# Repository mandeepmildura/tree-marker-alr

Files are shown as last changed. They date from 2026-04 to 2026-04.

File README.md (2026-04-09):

# Tree Marker ALR

GPS-triggered relay marker for precision orchard row planting.  
Fires an on-board relay at each tree grid intersection using RTK accuracy from an AgOpenGPS setup.

**Hardware:** [KinCony ALR](https://www.kincony.com/esp32-lora-sx1278-gateway.html) (ESP32-S3 + SSD1306 OLED + relay)  
**Position source:** AgOpenGPS / AgIO via WiFi UDP — no separate GPS needed  
**Accuracy:** ~2–5 cm with F9P RTK  

---

## How it works

```
F9P RTK GPS → AIO Teensy → UDP broadcast (port 9999) → AgIO on tablet
                                   ↓
                         ESP32-S3 on ALR listens on same WiFi
                         → parses $GNGGA → checks grid → fires relay
```

The ALR, your Windows tablet (AgIO), and AIO Teensy Ethernet all connect to the same phone hotspot in the tractor cab. No extra GPS wiring required.

---

## Hardware wiring

| Connection | Details |
|---|---|
| Power | 12–24V DC to ALR terminals |
| Relay output | ALR relay COM + NO → existing solenoid trigger circuit |
| WiFi | Same hotspot as AgOpenGPS tablet |

That's it. OLED, relay, and WiFi are all on-board.

---

## Setup

### 1. Install Arduino IDE dependencies

- Board package: **ESP32 by Espressif** — add this URL in board manager:  
  `https://raw.githubusercontent.com/espressif/arduino-esp32/gh-pages/package_esp32_index.json`
- Board: **ESP32S3 Dev Module**
- Libraries (Sketch → Manage Libraries):
  - `PubSubClient`
  - `Adafruit SSD1306`
  - `Adafruit GFX Library`

### 2. Edit config in `tree_marker.ino`

```cpp
const char* WIFI_SSID     = "YourHotspotName";
const char* WIFI_PASSWORD = "YourPassword";
const char* MQTT_HOST     = "your-id.s1.eu.hivemq.cloud";
const char* MQTT_USER     = "your-mqtt-user";
const char* MQTT_PASS     = "your-mqtt-pass";

const double ORIGIN_LAT   = -34.xxxxxx;   // First tree lat from AgOpenGPS
const double ORIGIN_LON   =  142.xxxxxx;  // First tree lon from AgOpenGPS
const double ROW_BEARING  =  90.0;        // AB line bearing from AgOpenGPS
const double ROW_SPACING  =   6.7;        // Metres
const double TREE_SPACING =   3.0;        // Metres
const int    NUM_ROWS     =  10;
const int    NUM_TREES    =  50;
```

### 3. Flash and test

1. Connect ALR via USB-C
2. Select **ESP32S3 Dev Module**, correct COM port
3. Upload
4. Open Serial Monitor (115200 baud)
5. OLED should show WiFi IP then "Waiting for AgIO"
6. Run AgOpenGPS simulation — drag cursor over a grid point — relay clicks

---

## MQTT topics

| Topic | Direction | Payload |
|---|---|---|
| `treemarker/status` | board → you | JSON heartbeat every 30s |
| `treemarker/hit` | board → you | `{"row":3,"tree":12,"dist":0.18,"lat":...,"lon":...}` |
| `treemarker/ota/url` | you → board | GitHub release .bin URL |
| `treemarker/ota/status` | board → you | `queued` / `starting` / `success` / `failed: ...` |
| `treemarker/restart` | you → board | Any payload triggers reboot |

---

## OTA firmware update via MQTT

1. Push a version tag to trigger a build and release:
   ```
   git tag v1.0.1
   git push origin v1.0.1
   ```
2. Wait for GitHub Actions to finish (~3 min)
3. Go to **Releases** → copy the `.bin` asset URL
4. Publish the URL to `treemarker/ota/url` via your MQTT client  
   (HiveMQ web client, MQTT Explorer, or Node-RED)
5. Board downloads, flashes, and reboots — monitor `treemarker/ota/status`

---

## Grid coordinate system

```
Tree (0,0) ─── Tree (0,1) ─── Tree (0,2) ───  ← Row 0 (ROW_BEARING direction)
    │                                          spacing = TREE_SPACING (3.0m)
Tree (1,0) ─── Tree (1,1) ─── Tree (1,2) ───  ← Row 1
    │
    ↕ ROW_SPACING (6.7m)
```

Origin `(ORIGIN_LAT, ORIGIN_LON)` = position of Tree (row=0, tree=0).  
`ROW_BEARING` = compass heading your rows run (get from AgOpenGPS AB line).

---

## Tuning

| Setting | Default | Notes |
|---|---|---|
| `HIT_RADIUS` | 0.35m | Tighten to 0.15m with solid RTK fix |
| `RELAY_PULSE_MS` | 600ms | Adjust for your solenoid / spray nozzle |
| `COOLDOWN_MS` | 2000ms | Prevents double-trigger on same tree |

---

## Project context

Part of the [AquaControl / Sunraysia Acres](https://github.com/mandeepMildura) precision ag toolkit.  
Mildura / Sunraysia region, Victoria, Australia.

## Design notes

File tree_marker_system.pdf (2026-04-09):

# GPS Tree Marker System

### Sunraysia Acres Pty Ltd — Mildura, Victoria

### Visual Feedback Options: KML Grid Overlay + Real-Time Web Dashboard

## 1. Project Overview

The Tree Marker system is a GPS-triggered paint marker that automatically fires a solenoid every time the tractor crosses a pre-calculated tree planting position. It piggybacks the existing AgOpenGPS RTK-GPS setup already on the tractor — no second GPS unit is needed.

Farm | Sunraysia Acres Pty Ltd, Mildura / Sunraysia, Victoria
Tractor | 1994–1997 Case IH 3230, 12V, hydrostatic power steering
GPS accuracy | Ardusimple SimpleRTK2B (u-blox F9P), RTK fix, ~2 cm
Controller | KinCony ALR board (ESP32-S3) — mounts on tractor
Marker | Existing electric paint solenoid, 12V — relay wired in series
Row spacing | 6.7 m between rows
Tree spacing | 3.0 m between trees within each row
Grid size | 10 rows × 50 trees = 500 tree positions per field

How it works — data flow

Ste p | What happens | Device
1 | F9P RTK GPS locks to ~2 cm fix | Ardusimple on AIO board
2 | AIO Teensy 4.1 forwards NMEA over Ethernet UDP → port 9999 | AIO v4.5 Standard
3 | AgIO (Windows tablet) receives position — also broadcasts to subnet | Tablet in cab
4 | KinCony ALR receives $GNGGA sentence over WiFi UDP | ALR board on tractor
5 | ALR compares GPS position against pre-calculated tree grid | ESP32-S3 firmware
6 | Within 35 cm of a tree point → GPIO 48 HIGH for 600 ms | ALR relay
7 | Relay fires solenoid → paint mark on ground | Paint sprayer

The tree grid is pre-calculated from a field survey origin point and stored in firmware. Grid maths uses flat-earth distance — accurate to <1 mm at orchard scales.

## 2. Why Visual Feedback Matters

The relay fires automatically and the OLED on the ALR board confirms each hit. However, for a commercial planting run across 500+ positions, the operator needs two additional things:

Need | Without feedback | With Options B + C
Pre-run check | No way to verify grid alignment before starting | KML overlay in Google Earth confirms grid matches real field boundaries
During run | Operator can't tell if a mark was missed | Live web dashboard shows each hit in real time — gaps are immediately visible
Post-run record | No permanent record of what was marked | Dashboard hit history + MQTT log = permanent GPS-stamped record of every mark
Missed-tree recovery | Must re-drive entire row | Dashboard shows exactly which tree was missed — drive back to that point only

## 3. Option C — KML Tree Grid Overlay

What it is: A standard KML file containing all 500 tree positions as placemarks and 10 row lines. Opens in Google Earth on any device. Used for pre-run alignment checks and post-run review. The file is auto-generated from the same grid parameters as the firmware — they are always in sync.

What the KML contains
- 500 yellow dot placemarks — one per tree, labelled R0T0 … R9T49
- 10 green row lines — one per row, showing direction of travel
- Document name and grid parameters embedded in description

How to use it — pre-run alignment check

Ste p | Action
1 | Open tree_grid.kml in Google Earth on phone or tablet
2 | Navigate to the field — the 500 dots appear on satellite imagery
3 | Compare dot positions against existing tree rows / fence lines
4 | If alignment is off, adjust ORIGIN_LAT, ORIGIN_LON or ROW_BEARING in firmware and regenerate
5 | When dots match reality, origin and bearing are confirmed — proceed to field run

How to use it — post-run review
- Open the KML in Google Earth after the run
- Cross-reference with the web dashboard hit history (Option B) to identify any missed positions
- Screenshot the overlay for farm records / neighbour sharing

Important note on coordinates

The KML currently uses placeholder coordinates (origin -34.200000, 142.150000). Before the farm run, a field survey must establish the real ORIGIN_LAT, ORIGIN_LON, and ROW_BEARING from the actual orchard. Once those are measured and entered, re-run make_kml.py (one command) and the KML updates automatically.

Field survey procedure

# | Measurement | Tool | Where to enter

1 | Stand the tractor at tree position (0,0) — first tree of first row. Record lat/lon from AgOpenGPS display. | AgOpenGPS + F9P RTK | ORIGIN_LAT, ORIGIN_LON in firmware
2 | Drive to the end of row 0 — last tree. Note the AgOpenGPS AB line bearing. | AgOpenGPS AB line bearing readout | ROW_BEARING in firmware (degrees, 0=N, 90=E)
3 | Count actual rows and trees if different from 10×50. | Walk the field | NUM_ROWS, NUM_TREES in firmware

## 4. Option B — Real-Time Web Dashboard

What it is: A single HTML file that opens in any browser (phone, tablet, laptop). It connects to the HiveMQ MQTT broker over a secure WebSocket and displays a live map. Every time the relay fires, a green marker drops on the map at the exact GPS coordinates of the hit. No app installation required.

How it works

Component | Technology | Role
Map display | Leaflet.js (open-source, offline-capable) | Renders satellite/street tile map with tree dots
Live updates | MQTT over WebSocket (port 8884, TLS) | Receives hit events from HiveMQ Cloud in real time
Broker | HiveMQ Cloud — eb65c13e....hivemq.cloud | Relays MQTT messages from ALR board to browser
Planned trees | GeoJSON generated from grid parameters | All 500 positions shown as grey dots on load
Hit markers | Green Leaflet markers, timestamped | Drop on map as each relay fires
No server | Pure browser HTML/JS — no backend needed | Open the file directly, works on any device

What you see on the dashboard
- Grey dots — all 500 planned tree positions (loaded at startup from grid maths)
- Green markers — confirmed hits, appearing in real time as the tractor drives
- Popup on click — shows Row, Tree, distance from centre, timestamp, lat/lon
- Hit counter — total marks fired this session
- Connection indicator — green/red dot showing MQTT link status

How to use it during a run

Ste p | Action
1 | Ensure phone/tablet is on the same WiFi hotspot as the ALR board
2 | Open tree_marker_dashboard.html in Chrome or Safari — map loads automatically
3 | Drive the first row — green markers should appear every 3.0 m

4 | If a grey dot stays grey after passing it, that tree was missed — note the Row/Tree number
5 | After completing all rows, screenshot the dashboard for farm records
6 | Hit history is also in HiveMQ Cloud — accessible from any browser after the run

MQTT message format (what the board sends)
Topic: treemarker/hit

{"row":3, "tree":12, "dist":0.18, "lat":-34.3171234, "lon":142.1562345, "hits":37}
Every hit publishes one JSON message. The dashboard subscribes to this topic and plots each message as a map marker. The full hit log is retained in HiveMQ for post-run review.

## 5. Combined Workflow — A to Z

Phase | Task | Tool | Status
Field survey | Drive to tree (0,0) with RTK lock. Record lat/lon + AB line bearing. | AgOpenGPS on tablet | Pending — do before farm run
Firmware update | Enter real ORIGIN_LAT, ORIGIN_LON, ROW_BEARING, NUM_ROWS, NUM_TREES. Flash board. | Arduino IDE / arduino-cli | Pending — after survey
KML update | Re-run make_kml.py with real coordinates. New KML in 5 seconds. | Python script in repo | Pending — after survey
Pre-run check | Open updated KML in Google Earth. Confirm 500 dots match real field. | Google Earth on phone | Pending — before run
Dashboard open | Open tree_marker_dashboard.html in browser on phone. | Any browser | Ready — build in progress
Farm run | Drive rows. Relay fires at each tree. Dashboard shows live hits. | Tractor + ALR board | Pending — farm visit
Post-run review | Screenshot dashboard. Cross-check KML vs green hit markers. | Dashboard + Google Earth | Pending — after run
Records | Full hit log in HiveMQ Cloud — row, tree, GPS coords, timestamp for every mark. | HiveMQ Cloud console | Automatic — already active

## 6. System Specifications

Firmware version | v1.0.0
Board | KinCony ALR — ESP32-S3-WROOM-1U N16R8
Relay | GPIO 48, AC250V / 10A, volt-free contact
OLED | SSD1306 128×64, I2C (SDA 39, SCL 38)
WiFi | 2.4 GHz 802.11n — connects to phone hotspot
UDP input | Port 9999 — $GNGGA from AgIO broadcast
Hit radius | 0.35 m from tree centre

Relay pulse | 600 ms ON per hit
Cooldown | 2000 ms minimum between same-spot hits
MQTT broker | HiveMQ Cloud (TLS port 8883)
Broker host | eb65c13ec8ab480a9c8492778fdddda8.s1.eu.hivemq.cloud
MQTT client ID | tree-marker-alr-01
Status topic | treemarker/status (heartbeat every 30 s)
Hit topic | treemarker/hit (JSON per relay fire)
OTA topic | treemarker/ota/url (send GitHub .bin URL to update)
Restart topic | treemarker/restart (any payload reboots board)
GitHub repo | github.com/mandeepmildura/tree-marker-alr

## 7. Next Steps

# | Task | Notes

1 | Complete field survey at Mildura farm | Measure ORIGIN_LAT/LON and ROW_BEARING with RTK fix
2 | Update firmware config + reflash | Use OTA update over MQTT — no USB cable needed at farm
3 | Regenerate KML with real coordinates | Run make_kml.py — takes 5 seconds
4 | Open KML in Google Earth — verify grid alignment | Do this before starting the planting run
5 | Open web dashboard on phone | Confirm MQTT connection indicator is green
6 | Drive first row slowly — confirm relay fires every 3.0 m | Watch dashboard for green hits and listen for relay clicks
7 | Proceed with full planting run | Dashboard provides real-time hit confirmation

Document prepared by Claude Code — April 2026 — For internal use, Sunraysia Acres Pty Ltd

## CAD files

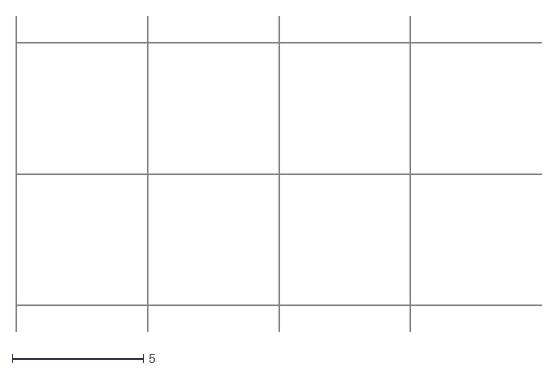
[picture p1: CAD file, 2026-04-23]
tests/sample_grid.dxf
20.0 x 12.0

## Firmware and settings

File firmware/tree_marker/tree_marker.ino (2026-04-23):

// ================================================================
//  Tree Row Marker — KinCony ALR (ESP32-S3)
//  Receives RTK position from AgOpenGPS via WiFi UDP
//  Fires on-board relay at each tree grid intersection
//
//  Repo:  https://github.com/mandeepMildura/tree-marker-alr
//  Board: KinCony ALR  https://www.kincony.com/esp32-lora-sx1278-gateway.html
//  IDE:   ESP32S3 Dev Module  (esp32 by Espressif, 2.x)
// ================================================================

#include <Arduino.h>
#include <WiFi.h>
#include <WiFiClientSecure.h>
#include <HTTPUpdate.h>
#include <PubSubClient.h>
#include <Wire.h>
#include <Adafruit_GFX.h>
#include <Adafruit_SSD1306.h>
#include <WebServer.h>
#include <Preferences.h>
#include <Update.h>
#include <HTTPClient.h>
#include <DNSServer.h>
#include <LittleFS.h>

// ── Firmware version (bumped on each release) ─────────────────
// 1.5.0 — DXF tree-grid upload: new /field/dxf endpoint parses LINE
//         entities, computes intersections, drives MODE_AB. Manual
//         anchor lat/lon supported as an alternative to AOG Field.txt.
//         Two outer perimeter lines exported as AgOpenGPS
//         TrackLines.txt (merge or stub) so autosteer tracks the
//         surveyed DXF edges.
#define FW_VERSION "1.5.0"

// ================================================================
//  COMPILED-IN DEFAULTS — overridden by Preferences after first save
// ================================================================
#define DEF_WIFI_SSID     "Mandeep"
#define DEF_WIFI_PASS     "rockyjungle161"
#define DEF_MQTT_HOST     "eb65c13ec8ab480a9c8492778fdddda8.s1.eu.hivemq.cloud"
#define DEF_MQTT_PORT     8883
#define DEF_MQTT_USER     "mandeep"
#define DEF_MQTT_PASS     "Gill@1977"
#define DEF_MQTT_CLIENT   "tree-marker-alr-01"
#define DEF_ORIGIN_LAT    -34.3166591
#define DEF_ORIGIN_LON    142.1562539
#define DEF_ROW_BEARING   180.0
#define DEF_ROW_SPACING   6.7
#define DEF_TREE_SPACING  3.0
#define DEF_NUM_ROWS      10
#define DEF_NUM_TREES     50
#define DEF_HIT_RADIUS    0.35
#define DEF_RELAY_PULSE   600

// Antenna → nozzle offset (v1.4.5). Both default to 0 so existing
// setups behave identically to v1.4.4 until calibrated.
#define DEF_FORE_AFT      0.0       // metres: positive = nozzle BEHIND antenna
#define DEF_LATERAL       0.0       // metres: positive = nozzle RIGHT of antenna centreline

// ── Grid mode ─────────────────────────────────────────────────
#define MODE_SIMPLE  0      // origin + bearing + spacings (bench/sim)
#define MODE_AB      1      // intersections[] grid (from AOG ABLines or DXF)

// Which source populated intersections[]. MODE_AB is the fire-detection
// mode; SRC_* distinguishes how the grid was built so boot can skip
// buildAbIntersections() when the source is DXF (no AB lines to resolve).
#define SRC_ABLINES  0
#define SRC_DXF      1

// Default AB-line names (match whatever you saved in AgOpenGPS)
#define DEF_ROW_NAME   "Row"
#define DEF_TREE_NAME  "Tree"

// Default DXF layer names for classifying LINE entities
#define DEF_ROW_LAYER  "Row"
#define DEF_TREE_LAYER "Tree"

// Default names for the two perimeter lines exported to TrackLines.txt
#define DEF_EDGE_ROW   "DXF-Row-Edge"
#define DEF_EDGE_TREE  "DXF-Tree-Edge"

// Max intersections we pre-compute and store in RAM.
// 2000 × 8 bytes = 16KB — comfortable on ESP32-S3.
#define MAX_INTERSECTIONS 2000

// Max boundary polygon vertices. 256 × 8 bytes = 2KB, and typical
// orchard boundaries have <100 points.
#define MAX_BOUNDARY 256

// ── AgIO UDP ──────────────────────────────────────────────────
#define UDP_PORT  8888

// ── MQTT topics ───────────────────────────────────────────────
#define T_STATUS      "treemarker/status"
#define T_HIT         "treemarker/hit"
#define T_OTA_URL     "treemarker/ota/url"
#define T_OTA_STATUS  "treemarker/ota/status"
#define T_RESTART     "treemarker/restart"

// ── Pin map ───────────────────────────────────────────────────
#define RELAY_PIN         48
#define OLED_SDA          39
#define OLED_SCL          38
#define SCREEN_W         128
#define SCREEN_H          64
#define SETUP_BUTTON_PIN   0       // DL button — hold at boot to force AP mode

// ── AP / setup mode ──────────────────────────────────────────
#define AP_SSID         "TreeMarker-Setup"
#define STA_TIMEOUT_MS  20000

// ── GitHub release API ───────────────────────────────────────
#define GH_LATEST_URL \
  "https://api.github.com/repos/mandeepMildura/tree-marker-alr/releases/latest"

// ================================================================
//  MUTABLE CONFIG (loaded from Preferences at boot)
// ================================================================
char   gWifiSsid[64];
char   gWifiPass[64];
char   gMqttHost[128];
int    gMqttPort;
char   gMqttUser[64];
char   gMqttPass[64];
double gOriginLat;
double gOriginLon;
double gRowBearing;
double gRowSpacing;
double gTreeSpacing;
int    gNumRows;
int    gNumTrees;
double gHitRadius;
int    gRelayPulse;
int    gUdpPort;
double gForeAft;         // + = nozzle behind antenna
double gLateral;         // + = nozzle right of centreline
double gHeading = 0;     // degrees, computed from consecutive fixes
double prevFixLat = 0, prevFixLon = 0;
bool   hasPrevFix = false;

// ── AB-mode state (loaded from NVS) ───────────────────────────
int    gGridMode;                 // MODE_SIMPLE or MODE_AB
char   gRowLineName[48];          // name of row AB line in ABLines.txt
char   gTreeLineName[48];         // name of tree AB line in ABLines.txt
double gFieldUtmE;                // (legacy — unused since v1.4.8)
double gFieldUtmN;                // (legacy — unused since v1.4.8)
int    gFieldZone;                // (legacy — unused since v1.4.8)
double gAnchorLat = 0;            // StartFix lat from AOG Field.txt
double gAnchorLon = 0;            // StartFix lon from AOG Field.txt
double gRowE, gRowN, gRowHdg;     // selected row AB line: point + heading(deg)
double gTreeE, gTreeN, gTreeHdg;  // selected tree AB line: point + heading(deg)
bool   gHasField  = false;        // true once Field.txt offsets are stored
bool   gHasLines  = false;        // true once both AB lines are selected
double gAbOriginE = 0;            // intersection of the two AB lines (row0/tree0) in local E/N
double gAbOriginN = 0;            // set by resolveActiveABLines()

// Raw ABLines.txt text held in RAM so user can re-pick lines without
// re-uploading. Persisted in NVS as "ab_raw" (<=3800 chars).
String gAbLinesRaw;

// ── DXF-mode state ────────────────────────────────────────────
// intersections[] may be populated from AOG ABLines (SRC_ABLINES) or
// from a DXF upload (SRC_DXF). The layer names are how we classify
// LINE entities inside the DXF; the edge names are how we tag the
// two outer perimeter lines that get exported to TrackLines.txt.
int  gGridSource = SRC_ABLINES;
char gRowLayer[24];
char gTreeLayer[24];
char gEdgeRowName[32];
char gEdgeTreeName[32];
// Generated TrackLines.txt content (merged or stubbed) — kept in
// NVS so the user can re-download without re-uploading the DXF.
String gTrackLinesOut;
// Outer row/tree perimeter line geometry (local E/N metres). Populated
// by pickOuterDxfLines() on each successful DXF upload. Heading is
// degrees in the AOG convention (0°=N, 90°=E, clockwise).
float  gEdgeRowX1 = 0, gEdgeRowY1 = 0, gEdgeRowX2 = 0, gEdgeRowY2 = 0;
float  gEdgeTreeX1 = 0, gEdgeTreeY1 = 0, gEdgeTreeX2 = 0, gEdgeTreeY2 = 0;
float  gEdgeRowHdg = 0, gEdgeTreeHdg = 0;
bool   gHasEdges = false;

// AB-mode geometry (declared up here so loadPrefs can populate them).
struct IPt { float e; float n; };
IPt  intersections[MAX_INTERSECTIONS];
int  numIntersections = 0;
IPt  boundary[MAX_BOUNDARY];
int  numBoundary = 0;
bool gHasBoundary = false;
int  lastRawIntersections = 0;  // pre-boundary-clip count, for UI

Preferences prefs;

void loadPrefs() {
  prefs.begin("tm", true);
  strlcpy(gWifiSsid,  prefs.getString("wifi_ssid",  DEF_WIFI_SSID).c_str(),  sizeof(gWifiSsid));
  strlcpy(gWifiPass,  prefs.getString("wifi_pass",  DEF_WIFI_PASS).c_str(),  sizeof(gWifiPass));
  strlcpy(gMqttHost,  prefs.getString("mqtt_host",  DEF_MQTT_HOST).c_str(),  sizeof(gMqttHost));
  gMqttPort    = prefs.getInt(   "mqtt_port",  DEF_MQTT_PORT);
  strlcpy(gMqttUser,  prefs.getString("mqtt_user",  DEF_MQTT_USER).c_str(),  sizeof(gMqttUser));
  strlcpy(gMqttPass,  prefs.getString("mqtt_pass",  DEF_MQTT_PASS).c_str(),  sizeof(gMqttPass));
  gOriginLat   = prefs.getDouble("origin_lat",  DEF_ORIGIN_LAT);
  gOriginLon   = prefs.getDouble("origin_lon",  DEF_ORIGIN_LON);
  gRowBearing  = prefs.getDouble("row_bearing", DEF_ROW_BEARING);
  gRowSpacing  = prefs.getDouble("row_spacing", DEF_ROW_SPACING);
  gTreeSpacing = prefs.getDouble("tree_space",  DEF_TREE_SPACING);
  gNumRows     = prefs.getInt(   "num_rows",    DEF_NUM_ROWS);
  gNumTrees    = prefs.getInt(   "num_trees",   DEF_NUM_TREES);
  gHitRadius   = prefs.getDouble("hit_radius",  DEF_HIT_RADIUS);
  gRelayPulse  = prefs.getInt(   "relay_pulse", DEF_RELAY_PULSE);
  gUdpPort     = prefs.getInt(   "udp_port",    UDP_PORT);
  gForeAft     = prefs.getDouble("fore_aft",    DEF_FORE_AFT);
  gLateral     = prefs.getDouble("lateral",     DEF_LATERAL);

  // AB-mode state
  gGridMode = prefs.getInt("grid_mode", MODE_SIMPLE);
  strlcpy(gRowLineName,  prefs.getString("row_name",  DEF_ROW_NAME ).c_str(), sizeof(gRowLineName));
  strlcpy(gTreeLineName, prefs.getString("tree_name", DEF_TREE_NAME).c_str(), sizeof(gTreeLineName));
  gFieldUtmE = prefs.getDouble("field_e", 0.0);
  gFieldUtmN = prefs.getDouble("field_n", 0.0);
  gFieldZone = prefs.getInt(   "field_z", 0);
  gAnchorLat = prefs.getDouble("anchor_lat", 0.0);
  gAnchorLon = prefs.getDouble("anchor_lon", 0.0);
  gHasField  = prefs.getBool(  "has_field", false);
  gHasLines  = prefs.getBool(  "has_lines", false);
  gRowE   = prefs.getDouble("row_e",   0);
  gRowN   = prefs.getDouble("row_n",   0);
  gRowHdg = prefs.getDouble("row_h",   0);
  gTreeE  = prefs.getDouble("tree_e",  0);
  gTreeN  = prefs.getDouble("tree_n",  0);
  gTreeHdg= prefs.getDouble("tree_h",  0);
  gAbLinesRaw = prefs.getString("ab_raw", "");
  gHasBoundary = prefs.getBool("has_bnd", false);
  numBoundary  = 0;
  if (gHasBoundary) {
    size_t want = prefs.getBytesLength("bnd_pts");
    if (want > 0 && want <= sizeof(boundary)) {
      prefs.getBytes("bnd_pts", boundary, want);
      numBoundary = want / sizeof(IPt);
    } else {
      gHasBoundary = false;
    }
  }

  // DXF-mode state
  gGridSource = prefs.getInt("grid_src", SRC_ABLINES);
  strlcpy(gRowLayer,     prefs.getString("row_lyr",   DEF_ROW_LAYER ).c_str(), sizeof(gRowLayer));
  strlcpy(gTreeLayer,    prefs.getString("tree_lyr",  DEF_TREE_LAYER).c_str(), sizeof(gTreeLayer));
  strlcpy(gEdgeRowName,  prefs.getString("edge_row",  DEF_EDGE_ROW ).c_str(),  sizeof(gEdgeRowName));
  strlcpy(gEdgeTreeName, prefs.getString("edge_tree", DEF_EDGE_TREE).c_str(),  sizeof(gEdgeTreeName));
  gTrackLinesOut = prefs.getString("trk_export", "");
  gHasEdges      = prefs.getBool(  "has_edges", false);
  gEdgeRowX1  = prefs.getFloat("erx1", 0);  gEdgeRowY1  = prefs.getFloat("ery1", 0);
  gEdgeRowX2  = prefs.getFloat("erx2", 0);  gEdgeRowY2  = prefs.getFloat("ery2", 0);
  gEdgeTreeX1 = prefs.getFloat("etx1", 0);  gEdgeTreeY1 = prefs.getFloat("ety1", 0);
  gEdgeTreeX2 = prefs.getFloat("etx2", 0);  gEdgeTreeY2 = prefs.getFloat("ety2", 0);
  gEdgeRowHdg = prefs.getFloat("erhdg", 0); gEdgeTreeHdg = prefs.getFloat("ethdg", 0);
  // When the grid source is DXF, intersections[] isn't rebuilt from
  // AB-line geometry — it's loaded straight from this cache.
  numIntersections = 0;
  lastRawIntersections = 0;
  if (gGridSource == SRC_DXF) {
    size_t want = prefs.getBytesLength("dxf_pts");
    if (want > 0 && want <= sizeof(intersections)) {
      prefs.getBytes("dxf_pts", intersections, want);
      numIntersections = want / sizeof(IPt);
      lastRawIntersections = numIntersections;
    }
  }

  prefs.end();
}

void saveAbPrefs() {
  prefs.begin("tm", false);
  prefs.putInt(   "grid_mode", gGridMode);
  prefs.putString("row_name",  gRowLineName);
  prefs.putString("tree_name", gTreeLineName);
  prefs.putDouble("field_e",   gFieldUtmE);
  prefs.putDouble("field_n",   gFieldUtmN);
  prefs.putInt(   "field_z",   gFieldZone);
  prefs.putDouble("anchor_lat", gAnchorLat);
  prefs.putDouble("anchor_lon", gAnchorLon);
  prefs.putBool(  "has_field", gHasField);
  prefs.putBool(  "has_lines", gHasLines);
  prefs.putDouble("row_e",  gRowE);
  prefs.putDouble("row_n",  gRowN);
  prefs.putDouble("row_h",  gRowHdg);
  prefs.putDouble("tree_e", gTreeE);
  prefs.putDouble("tree_n", gTreeN);
  prefs.putDouble("tree_h", gTreeHdg);
  // NVS string limit is ~4000 bytes — truncate defensively.
  String r = gAbLinesRaw;
  if (r.length() > 3800) r = r.substring(0, 3800);
  prefs.putString("ab_raw", r);
  prefs.putBool("has_bnd", gHasBoundary);
  if (gHasBoundary && numBoundary > 0) {
    prefs.putBytes("bnd_pts", boundary, numBoundary * sizeof(IPt));
  } else {
    prefs.remove("bnd_pts");
  }

  // DXF-mode state
  prefs.putInt(   "grid_src",  gGridSource);
  prefs.putString("row_lyr",   gRowLayer);
  prefs.putString("tree_lyr",  gTreeLayer);
  prefs.putString("edge_row",  gEdgeRowName);
  prefs.putString("edge_tree", gEdgeTreeName);
  // TrackLines.txt is small for two lines; guard against huge merged files.
  String t = gTrackLinesOut;
  if (t.length() > 3800) t = t.substring(0, 3800);
  prefs.putString("trk_export", t);
  prefs.putBool(  "has_edges", gHasEdges);
  prefs.putFloat("erx1", gEdgeRowX1);  prefs.putFloat("ery1", gEdgeRowY1);
  prefs.putFloat("erx2", gEdgeRowX2);  prefs.putFloat("ery2", gEdgeRowY2);
  prefs.putFloat("etx1", gEdgeTreeX1); prefs.putFloat("ety1", gEdgeTreeY1);
  prefs.putFloat("etx2", gEdgeTreeX2); prefs.putFloat("ety2", gEdgeTreeY2);
  prefs.putFloat("erhdg", gEdgeRowHdg);
  prefs.putFloat("ethdg", gEdgeTreeHdg);
  if (gGridSource == SRC_DXF && numIntersections > 0) {
    size_t want = numIntersections * sizeof(IPt);
    size_t wrote = prefs.putBytes("dxf_pts", intersections, want);
    if (wrote != want) {
      // NVS partition too small for the full grid — cache whatever fits.
      Serial.printf("[DXF] NVS cache truncated: wrote %u of %u bytes\n",
                    (unsigned)wrote, (unsigned)want);
    }
  } else if (gGridSource != SRC_DXF) {
    prefs.remove("dxf_pts");
  }

  prefs.end();
}

void saveGridPrefs() {
  prefs.begin("tm", false);
  prefs.putDouble("origin_lat",  gOriginLat);
  prefs.putDouble("origin_lon",  gOriginLon);
  prefs.putDouble("row_bearing", gRowBearing);
  prefs.putDouble("row_spacing", gRowSpacing);
  prefs.putDouble("tree_space",  gTreeSpacing);
  prefs.putInt(   "num_rows",    gNumRows);
  prefs.putInt(   "num_trees",   gNumTrees);
  prefs.putDouble("hit_radius",  gHitRadius);
  prefs.putInt(   "relay_pulse", gRelayPulse);
  prefs.putDouble("fore_aft",    gForeAft);
  prefs.putDouble("lateral",     gLateral);
  prefs.end();
}

void saveWifiPrefs() {
  prefs.begin("tm", false);
  prefs.putString("wifi_ssid", gWifiSsid);
  prefs.putString("wifi_pass", gWifiPass);
  prefs.putInt(   "udp_port",  gUdpPort);
  prefs.end();
}

// ── Objects ───────────────────────────────────────────────────
WiFiUDP           udp;
WiFiClientSecure  tlsClient;
PubSubClient      mqtt(tlsClient);
Adafruit_SSD1306  oled(SCREEN_W, SCREEN_H, &Wire, -1);
WebServer         webServer(80);
DNSServer         dnsServer;
bool              apMode = false;
bool              otaRebootPending = false;
unsigned long     otaRebootAt = 0;

// ── Grid ──────────────────────────────────────────────────────
const double M_PER_DEG_LAT = 111320.0;
double mPerDegLon;
double bearingRad, perpBearingRad;

struct Point { double lat; double lon; };
Point grid[20][100];   // [row][tree]  max 20x100

// (intersections[], boundary[], IPt, counts — all declared up top near
// the global config so loadPrefs() can populate them on boot.)

// Ring buffer of the last 20 fires — for the dashboard "Recent Hits" card
// and field calibration. Ephemeral (cleared on reboot).
#define HIT_LOG_CAP 20
struct HitLog { int row; int tree; float dist; double lat; double lon; float heading; unsigned long ms; };
HitLog hitLog[HIT_LOG_CAP];
int    hitLogHead  = 0;   // next write slot (oldest gets overwritten)
int    hitLogCount = 0;

// Forward decls — full definitions live further down next to the rest
// of the AB-mode helpers. Needed because checkGrid() / handleGrid() are
// above them and Arduino's auto-prototyping isn't reliable with
// reference parameters.
void latLonToLocal(double lat, double lon, double& localE, double& localN);
void localToLatLon(double localE, double localN, double& lat, double& lon);
void utmToLatLon(double utmE, double utmN, int zone, double& lat, double& lon);

// ── State ─────────────────────────────────────────────────────
bool   relayActive    = false;
unsigned long relayStart    = 0;
unsigned long lastHit       = 0;
int    lastRow   = -1, lastTree  = -1;
// Closest-approach tracker (v1.4.4+). Replaces the older inside-radius debounce.
// approachIdx: flat tree index (r*numTrees+t) we're currently approaching.
// approachMinD: smallest distance seen since approachIdx was locked.
// approachFired: set after a fire so the same tree can't re-fire until the
//                tractor moves out of range (nearIdx < 0 clears everything).
int    approachIdx   = -1;
float  approachMinD  = 1e9f;
bool   approachFired = false;
double lastDist  =  0;
double curLat    =  0, curLon   =  0;
bool   gpsFix    = false;
unsigned long lastFixMs     = 0;
int    totalHits            = 0;
unsigned long lastHeartbeat = 0;
unsigned long lastMachineSend = 0;
bool   otaPending   = false;
String otaUrl       = "";
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
void loop() {
  // Relay off after pulse
  if (relayActive && millis() - relayStart > (unsigned long)gRelayPulse) {
    digitalWrite(RELAY_PIN, LOW);
    relayActive = false;
  }

  // OTA
  if (otaPending) doOTA();
  if (otaRebootPending && millis() >= otaRebootAt) {
    Serial.println("Rebooting after upload OTA...");
    delay(100);
    ESP.restart();
  }

  // Web server (always)
  webServer.handleClient();

  // AP setup mode: only run web + DNS. Skip GPS / MQTT / OLED updates below.
  if (apMode) {
    dnsServer.processNextRequest();
    static unsigned long lastApOled = 0;
    if (millis() - lastApOled > 500) {
      lastApOled = millis();
      oled.clearDisplay();
      oled.setCursor(0, 0);
      oled.setTextSize(1);
      oled.println("SETUP MODE");
      oled.println(AP_SSID);
      oled.println("192.168.4.1");
      oled.display();
    }
    return;
  }

  // MQTT keep-alive
  if (WiFi.status() == WL_CONNECTED) {
    if (!mqtt.connected()) mqttConnect();
    mqtt.loop();
  }

  // Read UDP from AgIO / AgOpenGPS
  int pkt = udp.parsePacket();
  if (pkt > 0) {
    uint8_t buf[256];
    int len = udp.read(buf, sizeof(buf) - 1);
    double lat, lon;
    if (parsePGN100(buf, len, lat, lon)) {
      // AOG NAV PGN 100 — works in RTK and simulator mode
      gpsFix = true; curLat = lat; curLon = lon;
      lastFixMs = millis();
      updateHeading(lat, lon);
      double nozLat, nozLon;
      applyNozzleOffset(lat, lon, nozLat, nozLon);
      checkGrid(nozLat, nozLon);
    } else {
      // Fallback: NMEA text ($GNGGA / $GPGGA) if AgIO NMEA-out enabled
      buf[len] = '\0';
      char* line = strtok((char*)buf, "\r\n");
      while (line) {
        if (parseGGA(line, lat, lon)) {
          gpsFix = true; curLat = lat; curLon = lon;
          lastFixMs = millis();
          updateHeading(lat, lon);
          double nozLat, nozLon;
          applyNozzleOffset(lat, lon, nozLat, nozLon);
          checkGrid(nozLat, nozLon);
        }
        line = strtok(nullptr, "\r\n");
      }
    }
  }

  // GPS fix timeout
  if (gpsFix && millis() - lastFixMs > 3000) {
    gpsFix = false;
    Serial.println("AgIO position lost");
  }

  // MQTT heartbeat every 30s
  if (millis() - lastHeartbeat > 30000) {
    lastHeartbeat = millis();
    char hb[120];
    snprintf(hb, sizeof(hb),
      "{\"online\":true,\"fw\":\"%s\",\"uptime\":%lu,\"hits\":%d,\"fix\":%s}",
      FW_VERSION, millis()/1000, totalHits, gpsFix?"true":"false");
    mqtt.publish(T_STATUS, hb, true);
  }

  // PGN 239 to AgOpenGPS every 100ms
  if (WiFi.status() == WL_CONNECTED && millis() - lastMachineSend > 100) {
    sendMachinePGN();
    lastMachineSend = millis();
  }

  // OLED every 400ms
  static unsigned long lastOled = 0;
  if (millis() - lastOled > 400) {
    updateOLED();
    lastOled = millis();
  }
}

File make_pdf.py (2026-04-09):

"""
make_pdf.py  —  Generates Tree Marker System overview PDF
Output:  tree_marker_system.pdf
"""

from reportlab.lib.pagesizes import A4
from reportlab.lib import colors
from reportlab.lib.units import mm
from reportlab.lib.styles import getSampleStyleSheet, ParagraphStyle
from reportlab.lib.enums import TA_LEFT, TA_CENTER, TA_JUSTIFY
from reportlab.platypus import (
    SimpleDocTemplate, Paragraph, Spacer, Table, TableStyle,
    HRFlowable, KeepTogether
)

OUT = "C:/Users/msgil/GIT/tree-marker-alr/tree_marker_system.pdf"
W, H = A4

# ── Colours ───────────────────────────────────────────────────
GREEN   = colors.HexColor("#2e7d32")
LGREEN  = colors.HexColor("#e8f5e9")
BLUE    = colors.HexColor("#1565c0")
LBLUE   = colors.HexColor("#e3f2fd")
ORANGE  = colors.HexColor("#e65100")
LORANGE = colors.HexColor("#fff3e0")
GREY    = colors.HexColor("#424242")
LGREY   = colors.HexColor("#f5f5f5")
WHITE   = colors.white

# ── Styles ────────────────────────────────────────────────────
base = getSampleStyleSheet()

def S(name, **kw):
    return ParagraphStyle(name, **kw)

title_s   = S("title_s",   fontSize=24, textColor=WHITE,   leading=30, alignment=TA_CENTER, fontName="Helvetica-Bold")
sub_s     = S("sub_s",     fontSize=11, textColor=LGREY,   leading=16, alignment=TA_CENTER, fontName="Helvetica")
h1_s      = S("h1_s",      fontSize=14, textColor=WHITE,   leading=18, fontName="Helvetica-Bold", spaceAfter=2)
h2_s      = S("h2_s",      fontSize=12, textColor=BLUE,    leading=16, fontName="Helvetica-Bold", spaceBefore=10, spaceAfter=4)
h3_s      = S("h3_s",      fontSize=10, textColor=GREY,    leading=14, fontName="Helvetica-Bold", spaceBefore=6, spaceAfter=2)
body_s    = S("body_s",    fontSize=9,  textColor=GREY,    leading=14, alignment=TA_JUSTIFY, fontName="Helvetica")
bullet_s  = S("bullet_s",  fontSize=9,  textColor=GREY,    leading=14, fontName="Helvetica",
               leftIndent=12, bulletIndent=0, spaceBefore=1)
code_s    = S("code_s",    fontSize=8,  textColor=colors.HexColor("#1a237e"),
               fontName="Courier", leading=12, leftIndent=8, backColor=LGREY)
caption_s = S("caption_s", fontSize=8,  textColor=colors.HexColor("#757575"),
               leading=11, alignment=TA_CENTER, fontName="Helvetica-Oblique")
label_s   = S("label_s",   fontSize=9,  textColor=GREY, fontName="Helvetica-Bold", leading=13)
value_s   = S("value_s",   fontSize=9,  textColor=GREY, fontName="Helvetica",      leading=13)

def rule(color=BLUE, thickness=0.5):
    return HRFlowable(width="100%", thickness=thickness, color=color, spaceAfter=6, spaceBefore=2)

def gap(n=6):
    return Spacer(1, n)

def B(text, style=bullet_s):
    return Paragraph(f"<bullet>&bull;</bullet> {text}", style)

def section_banner(text, bg=BLUE):
    data = [[Paragraph(text, h1_s)]]
    t = Table(data, colWidths=[170*mm])
    t.setStyle(TableStyle([
        ("BACKGROUND", (0,0), (-1,-1), bg),
        ("TOPPADDING",    (0,0), (-1,-1), 8),
        ("BOTTOMPADDING", (0,0), (-1,-1), 8),
        ("LEFTPADDING",   (0,0), (-1,-1), 10),
        ("RIGHTPADDING",  (0,0), (-1,-1), 10),
        ("ROUNDEDCORNERS", [4]),
    ]))
    return t

def info_box(rows, bg=LGREY, border=BLUE):
    """rows = list of (label, value) tuples"""
    data = [[Paragraph(l, label_s), Paragraph(v, value_s)] for l, v in rows]
    t = Table(data, colWidths=[55*mm, 110*mm])
    t.setStyle(TableStyle([
        ("BACKGROUND",    (0,0), (-1,-1), bg),
        ("LINEBELOW",     (0,0), (-1,-2), 0.3, colors.HexColor("#cccccc")),
        ("TOPPADDING",    (0,0), (-1,-1), 4),
        ("BOTTOMPADDING", (0,0), (-1,-1), 4),
        ("LEFTPADDING",   (0,0), (-1,-1), 8),
        ("RIGHTPADDING",  (0,0), (-1,-1), 8),
        ("BOX",           (0,0), (-1,-1), 1, border),
    ]))
    return t

def highlight_box(text, bg=LGREEN, border=GREEN):
    data = [[Paragraph(text, body_s)]]
    t = Table(data, colWidths=[170*mm])
    t.setStyle(TableStyle([
        ("BACKGROUND",    (0,0), (-1,-1), bg),
        ("BOX",           (0,0), (-1,-1), 1, border),
        ("TOPPADDING",    (0,0), (-1,-1), 8),
        ("BOTTOMPADDING", (0,0), (-1,-1), 8),
        ("LEFTPADDING",   (0,0), (-1,-1), 10),
        ("RIGHTPADDING",  (0,0), (-1,-1), 10),
    ]))
    return t

def flow_table(rows, col_widths, header_bg=BLUE):
    data = []
    styles_list = [
        ("BACKGROUND",    (0,0), (-1,0),  header_bg),
        ("TEXTCOLOR",     (0,0), (-1,0),  WHITE),
        ("FONTNAME",      (0,0), (-1,0),  "Helvetica-Bold"),
        ("FONTSIZE",      (0,0), (-1,-1), 8),
        ("TOPPADDING",    (0,0), (-1,-1), 4),
        ("BOTTOMPADDING", (0,0), (-1,-1), 4),
        ("LEFTPADDING",   (0,0), (-1,-1), 6),
        ("RIGHTPADDING",  (0,0), (-1,-1), 6),
        ("ROWBACKGROUNDS",(0,1), (-1,-1), [WHITE, LGREY]),
        ("GRID",          (0,0), (-1,-1), 0.3, colors.HexColor("#bdbdbd")),
        ("VALIGN",        (0,0), (-1,-1), "TOP"),
    ]
    for r in rows:
        data.append([Paragraph(str(c), body_s) for c in r])
    t = Table(data, colWidths=col_widths)
    t.setStyle(TableStyle(styles_list))
    return t

# ══════════════════════════════════════════════════════════════
#  BUILD STORY
# ══════════════════════════════════════════════════════════════
story = []

# ── Cover banner ──────────────────────────────────────────────
cover_data = [[
    Paragraph("GPS Tree Marker System", title_s),
    Paragraph("Sunraysia Acres Pty Ltd", sub_s),
    Paragraph("Visual Feedback Options — Option B &amp; C", sub_s),
    Paragraph("KML Grid Overlay  +  Real-Time Web Dashboard", sub_s),
]]
cover = Table([[
    Paragraph("GPS Tree Marker System", title_s),
]], colWidths=[170*mm])
cover.setStyle(TableStyle([
    ("BACKGROUND",    (0,0), (-1,-1), GREEN),
    ("TOPPADDING",    (0,0), (-1,-1), 18),
    ("BOTTOMPADDING", (0,0), (-1,-1), 6),
    ("LEFTPADDING",   (0,0), (-1,-1), 10),
    ("RIGHTPADDING",  (0,0), (-1,-1), 10),
]))
story.append(cover)

sub_banner_data = [
    [Paragraph("Sunraysia Acres Pty Ltd  —  Mildura, Victoria", sub_s)],
    [Paragraph("Visual Feedback Options: KML Grid Overlay + Real-Time Web Dashboard", sub_s)],
]
sub_banner = Table(sub_banner_data, colWidths=[170*mm])
sub_banner.setStyle(TableStyle([
    ("BACKGROUND",    (0,0), (-1,-1), colors.HexColor("#1b5e20")),
    ("TOPPADDING",    (0,0), (-1,-1), 5),
    ("BOTTOMPADDING", (0,0), (-1,-1), 10),
    ("LEFTPADDING",   (0,0), (-1,-1), 10),
    ("RIGHTPADDING",  (0,0), (-1,-1), 10),
]))
story.append(sub_banner)
story.append(gap(12))

# ── 1. Project Overview ───────────────────────────────────────
story.append(section_banner("1.  Project Overview"))
story.append(gap(6))
story.append(Paragraph(
    "The Tree Marker system is a GPS-triggered paint marker that automatically fires a solenoid "
    "every time the tractor crosses a pre-calculated tree planting position. It piggybacks the "
    "existing AgOpenGPS RTK-GPS setup already on the tractor — no second GPS unit is needed.",
    body_s))
story.append(gap(8))
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

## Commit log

2026-04-09 Initial commit — Tree Marker ALR firmware v1.0.0
2026-04-09 v1.0.1 — real farm coords, PGN239, web dashboard
    - Origin updated to -34.3166591, 142.1562539 (Sunraysia Acres)
    - Row bearing corrected to 180.0 degrees (south)
    - Added PGN 239 section feedback to AgOpenGPS at 10Hz
    - Added real-time web dashboard (Leaflet + MQTT WebSocket)
    - Added KML tree grid generator
    - Added GPS simulator for desk testing
    [make_pdf.py, sim_gps.py, tree_marker.ino]
2026-04-09 Fix CI: pin esp32 core to 2.0.17 (firmware requires 2.x)
2026-04-09 v1.1.0 — on-board web server, NVS config, dashboard fixes
    - WebServer (port 80) with full single-page config UI
    - Preferences NVS: persist grid params and WiFi credentials
    - /api/status JSON endpoint (polled every 2s by embedded page)
    - /relay POST to test-fire relay from browser
    - /config/grid POST to update tree grid live (rebuilds immediately)
    - /config/wifi POST saves credentials and reboots
    - Dashboard: real farm coords, Esri satellite maxNativeZoom:19
    [tree_marker.ino]
2026-04-09 v1.2.0 — Stitch-inspired web UI (light theme, Space Grotesk)
2026-04-09 Fix CI: use arrow fns in PROGMEM page to avoid Arduino preprocessor false prototype extraction
    [tree_marker.ino]
2026-04-09 v1.2.1 — fix OTA: use dedicated WiFiClientSecure to avoid MQTT client conflict
    [tree_marker.ino]
2026-04-09 v1.2.2 — listen on UDP 8888 to match AgIO GPS output port
2026-04-09 v1.2.3 — web UI: UDP port config + OTA flash button
2026-04-09 v1.2.4 — parse AgIO binary PGN 200 for GPS position (was expecting NMEA)
2026-04-09 v1.2.5 — add UDP serial debug dump to diagnose PGN format
2026-04-21 v1.3.0 — captive-portal AP for WiFi setup + 4-way OTA
    When saved WiFi is unreachable (or DL button held at boot), the board
    falls back to a SoftAP 'TreeMarker-Setup' with DNS captive portal.
    A minimal setup page at 192.168.4.1 scans nearby SSIDs and lets the
    operator enter new credentials without reflashing. This unblocks field
    recovery when the hotspot name/password changes.
    OTA now has four paths:
    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
2026-04-21 v1.3.1 — decode AgOpenGPS PGN 100 (NAV) for simulator + RTK
    AOG broadcasts its current position as PGN 0x64 with a 24-byte
    payload: longitude (double LE, bytes 0-7) + latitude (double LE,
    bytes 8-15) + heading/speed fields. This is what flows in AOG
    simulator mode — there is no NMEA to forward, so the existing
    $GNGGA parser never saw anything. Real RTK also emits PGN 100 once
    AgIO has a fix, so this works in both modes.
    Previous parsePGN200 was misnamed: PGN 200 is AgIO's Hello/heartbeat
    (3-byte payload), never GPS position. Replaced with parsePGN100.
    Drop the per-packet UDP hex dump and per-line NMEA debug prints —
    they were diagnostic for the v1.2.4-v1.2.5 parsing hunt and are
    nois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
    [sim_gps.py, tree_marker.ino]
2026-04-21 v1.3.2 — debounce hits: fire once per tree entry, not per pulse
    Previously the relay re-triggered every gRelayPulse+200ms whenever
    the tractor was inside any tree's hit radius. If the tractor stopped
    within that radius (common near headlands, or while idling on a
    tree), the relay kept clicking.
    Now checkGrid() tracks the nearest tree currently inside the radius
    (insideRow / insideTree). A fire is only issued on entering a NEW
    tree. Once the tractor exits every radius, insideRow/Tree clears so
    re-entry can fire again. Also switched from "first match" to
    "nearest match" so overlapping radii pick the closer target.
    [tree_marker.ino]
2026-04-21 v1.3.3 — fix dashboard Config form wiping user edits
    The 2-second status poll overwrote every Config input on each tick,
    so typing a new value (e.g. hit radius) and pausing before clicking
    Save caused the poll to silently reset the field to the current
    board value. Save then saved the unchanged value and the change
    appeared to "not work".
    Now the form is only populated on initial load (first poll) and
    when the user explicitly navigates back to the Config tab. The
    server snapshot is still kept in window._cfg so tab-reopen can
    refresh from it. Status-panel readouts continue updating live.
    [tree_marker.ino]
2026-04-21 v1.4.0 — import AB lines + boundary-UTM grid from AgOpenGPS
    Adds a second gridding mode that mirrors how AgOpenGPS itself thinks
    about the field. Users drive two AB lines in AOG (one along the tree
    direction, one along the row direction), save them with the configured
    names, then drag ABLines.txt and Field.txt onto the new Field tab in
    the dashboard. The board parses the two files, picks the two lines by
    name, converts everything to UTM local coordinates, and computes the
    full intersection grid (one relay fire per crossing). No fixed origin,
    no bearing guesswork, no field-shape assumptions.
    Why two modes instead of a full cutover:
    MODE_SIMPLE stays for bench / sim_gps.py testing where A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
    [tree_marker.ino]
2026-04-21 v1.4.0 fixup: hoist intersections[] above checkGrid() so Arduino preprocessor can see it. No behavioral change.
    [tree_marker.ino]
2026-04-21 v1.4.0 fixup 2: explicit forward decl for latLonToLocal so checkGrid() compiles (Arduino auto-proto skipped it).
    [tree_marker.ino]
2026-04-21 v1.4.1 — Recent Hits live log on Status tab
    Adds a scrolling 'Recent Hits' card showing the last 20 fires
    (row, tree, distance, age) with the newest at the top. Updates
    live — fetched whenever the total hit count changes, so no wasted
    polling.
    Implementation: 20-slot ring buffer in RAM (cleared on reboot),
    /api/hits JSON endpoint, small card + render JS on the dashboard.
    This is useful field-side: you can see on the tablet at a glance
    which tree fired and how close the pass was, without watching
    serial or MQTT. Also serves as the foundation for the
    bidirectional calibration log in v1.4.4.
    [tree_marker.ino]
2026-04-21 v1.4.2 — Map tab with satellite view (Leaflet)
    Adds a live map to the on-board dashboard at /#map with:
    • Esri World_Imagery satellite, CartoDB dark, OpenStreetMap
    (togglable via the top-right layer control)
    • Planned tree grid plotted as yellow circles (Row/Tree tooltip)
    • Last-20 hits as green circles (distance + row/tree tooltip)
    • Live tractor marker in blue, updated from /api/status every 2s
    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
2026-04-21 v1.4.2 fixup: build /api/grid response in memory instead of chunked
    The chunked sendContent() loop was truncating at random points
    (11-13KB) due to buffer/timing interaction in the WebServer library
    when called in a tight loop. Simpler and more reliable to build the
    full ~20KB JSON in a reserved String and send it as one response.
    [tree_marker.ino]
2026-04-21 v1.4.3 — optional Boundary.txt clips the grid to the field shape
    Adds a third slot to the Field-tab upload for AOG's Boundary.txt. When
    present, the polygon (in local E/N) is stored in NVS and used as a
    point-in-polygon filter during buildAbIntersections(): only
    intersections inside the boundary survive. The raw count is still
    tracked so the UI can show "287 intersections (412 before boundary clip)"
    for sanity.
    Boundary format is forgiving — any line with two comma-separated
    numbers is taken as (easting, northing), skipping $headers. Handles
    both v5-style and v6-style AOG files without knowing which you've got.
    Dashboard updates:
    • Field tab: third file picker (labelled optional)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
    [tree_marker.ino]
2026-04-21 v1.4.3 fixup: hoist IPt/boundary/intersections globals above loadPrefs
    loadPrefs() now reads boundary state from NVS, so its declarations have
    to be visible before loadPrefs in the translation unit. Moved them up
    to the other global config block; no behavior change.
    [tree_marker.ino]
2026-04-21 v1.4.4 — closest-approach triggering (fire at exact crossing point)
    Previously the relay fired the instant the tractor entered the
    hit-radius of a tree. That worked but the trigger point depended on
    the approach angle — hitting a tree head-on vs passing tangentially
    produced marks at different geometric moments.
    Now we track the nearest tree's distance across fixes and fire at
    the exact moment it stops decreasing: the geometric closest point.
    gHitRadius is reinterpreted as a *pass threshold* — closest
    approaches wider than this are ignored (e.g. a tree 2m off the
    tractor's path in an adjacent row doesn't fire).
    State machine per pass:
    • locate nearest tree within 2.5×radius+0.5m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
    [tree_marker.ino]
2026-04-21 v1.4.5 — antenna→nozzle offset + bidirectional calibration
    Real-world concern: the GPS antenna is usually on the cab roof, but
    the paint-marking nozzle is somewhere else on the tractor — typically
    a boom behind the cab, sometimes offset to one side. With no
    compensation, every mark lands where the antenna was when the tree
    was crossed, not where the nozzle was. That can be meters off.
    This version fixes that. Two new config values — both default to 0
    so existing setups are unchanged — live in NVS:
    foreAft (m): positive = nozzle is BEHIND the antenna along the
    tractor's direction of travel
    lateral (m): positive = nozzle is RIGHT of the antenna centreline
    On ever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
    [tree_marker.ino]
2026-04-22 v1.4.6 — map compass + rotating tractor arrow + virtual nozzle marker
    Makes the Map tab calibration-aware at a glance. A compass rose sits in
    the bottom-left corner so the map's north-up orientation is obvious. The
    tractor marker is now a blue arrow that rotates with heading and shows
    the current bearing as a compass label ("180° S"). When the
    antenna→nozzle offset is non-zero, an amber dot + dashed tether appears
    at the computed virtual-nozzle position — i.e. exactly where paint will
    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
2026-04-22 v1.4.7 — field upload returns JSON errors with file preview
    When Field.txt parsing failed, the server sent plain-text "Could not..."
    and the client called .json() on it, surfacing a cryptic "SyntaxError:
    Unexpected token 'C'" instead of the actual reason. Now every
    /field/upload error path returns {ok:false, error, detail} with
    application/json, and the UI shows the real message in red plus a
    120-char preview of what the parser actually received — so a
    malformed or unexpected Field.txt is immediately diagnosable.
    [tree_marker.ino]
2026-04-22 v1.4.8 — switch field projection to StartFix anchor + flat earth
    AOG v6+ stores $Offsets as 0,0 and puts the actual reference point at
    StartFix. ABLines.txt / Boundary.txt coordinates are meters relative to
    StartFix, not UTM absolutes. The previous parser required a UTM zone in
    $Offsets, which modern files don't have, so every real AOG field-folder
    upload hit "Could not parse Field.txt."
    Replace the UTM projection path with a flat-earth anchor:
    - parseFieldTxt now reads StartFix lat/lon as the anchor
    - latLonToLocal / localToLatLon use (dN/111320, dE/(111320·cos(lat)))
    — sub-millimetre accurate within 5km of the anchor
    - NVS adds anchor_lat / anchor_lon alongside the legacy UTM keys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
    [tree_marker.ino]
2026-04-22 v1.4.9 — gate Origin/Bearing fields by grid mode
    In AB mode, the grid's origin and row heading are derived from the
    AB-line anchor and the Row AB line — editing them on the Config tab had
    no effect but looked like it should. Now the Grid Parameters card is
    split into a "Simple Mode — Origin & Bearing" subgroup and a "Plant
    Pattern & Detection" subgroup, plus a mode banner at the top. When AB
    mode is active with resolved lines, the three Simple-only inputs go
    disabled with an inline "(auto from AB)" hint, and the banner shows
    the currently-active anchor and row heading so the user can see where
    the grid is actually being built from.
    /api/status cfg now also carries anchorLat, anchorLon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
    [tree_marker.ino]
2026-04-22 v1.4.10 — entire Grid Parameters card is Simple-mode only
    v1.4.9 only disabled Origin & Bearing in AB mode, but Plant Pattern &
    Detection (row/tree spacing, counts, hit radius, relay pulse) were
    still editable — and edits did apply, which is confusing when AB mode
    is supposed to be fully driven by AgOpenGPS. Now every field in the
    Grid Parameters card plus the Save button go disabled in AB mode, and
    the banner + footer note both tell the user to switch to Simple mode
    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
2026-04-22 v1.4.11 — fix AB grid alignment + show AB lines on map
    Grid was drifting vs AgOpenGPS because buildAbIntersections() stepped
    via a hard 90° rotation of each AB line. If the two AB lines weren't
    exactly perpendicular (or were drawn pointing "the other way"), the
    generated grid mirrored or offset relative to the real trees.
    Now resolveActiveABLines() solves the Row/Tree line-line intersection
    once as the true row-0/tree-0 anchor, and the builder steps along each
    line's own unit vector (gTreeSpacing along Row, gRowSpacing along Tree).
    Works for any angle between the two lines.
    Also:
    - /api/grid returns rowLine and treeLine segments; map overlays them
    (red = Row AB, purple = Tree AB) so m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
    [tree_marker.ino]
2026-04-22 v1.4.12 — AB mode: spacings + counts editable
    ABLines.txt doesn't carry row/tree spacing or grid counts, only line
    directions. In v1.4.11 those fields were locked behind the simple-only
    class, so in AB mode the user was stuck with whatever values happened
    to be in NVS — and had no way to size the grid to their actual block.
    Now Row Spacing, Tree Spacing, Number of Rows, and Trees per Row are
    editable in AB mode. Backend already rebuilds AB intersections on save
    (handleConfigGrid), so changes apply instantly.
    Origin, Bearing, and Hit Radius stay Simple-only — origin and bearing
    derive from the AB-line intersection, and hit radius isn't in scope.
    Banner now documents the convention: d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
    [tree_marker.ino]
2026-04-23 v1.5.0 — DXF tree-grid upload + TrackLines.txt export
    Adds a new /field/dxf endpoint that streams a user-supplied DXF file,
    parses LINE entities (layers Row / Tree by default), computes pairwise
    intersections, and populates the existing MODE_AB intersections[] array
    so fire detection works unchanged. Anchor comes from either an uploaded
    AgOpenGPS Field.txt or a manually entered lat/lon.
    Also exports the two outermost perimeter lines as a TrackLines.txt that
    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
    [sample_grid.dxf]
2026-04-23 Match real AOG v6 TrackLines.txt format
    User shared a real AgOpenGPS TrackLines.txt sample:
    $TrackLines
    <name>
    <heading in radians>
    <ptA.E>,<ptA.N>
    <ptB.E>,<ptB.N>
    <nudge offset>
    <mode> (2 = AB in the sample)
    <visible> (True/False)
    <trailing flag> (0)
    Rewrite formatTrackRecord to emit CRLF-delimited 8-line records with
    heading in radians (was degrees) and points as "E,N" on one line each.
    Emit a single "$TrackLines" header at the top of the file (was
    "$TrackLine" per record). Update stripPriorEdges to walk the real
    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
    [tree_marker.ino]
